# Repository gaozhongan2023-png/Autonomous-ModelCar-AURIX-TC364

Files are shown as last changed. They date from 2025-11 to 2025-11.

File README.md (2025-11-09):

# Autonomous-ModelCar-AURIX-TC364

A high-speed autonomous model car project based on the Infineon AURIX TC364 microcontroller.  
The system performs real-time lane detection, path fitting, and closed-loop PID control using onboard image processing, achieving stable tracking at speeds up to **3.3 m/s**.

---

## Project Overview

This project was developed for a vision-based autonomous car competition.  
The model car (approximately 25 cm in length) drives on a track resembling real road lanes.  
It detects both left and right lane boundaries using a custom image processing algorithm and performs high-speed closed-loop control completely offline on the MCU.

The same algorithm can also be simulated on a PC using OpenCV for debugging and visualization.

---

## Demonstration

**1. Real Vehicle Running on Track**

<p align="center">
  
</p>

**2. PC Simulation Visualization**

<p align="center">
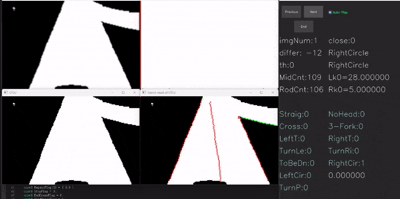
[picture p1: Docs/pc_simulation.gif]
  
</p>

---

## Repository Structure

| Directory / File | Description |
|---|---|
| **Docs/** | Supporting materials |
| `Docs/real_car.gif` | Real car driving demonstration |
| `Docs/pc_simulation.gif` | OpenCV simulation demonstration |
| **MCU/** | Embedded control code for Infineon AURIX TC364 |
| `MCU/CODE/` | User-written application logic: control algorithms, image processing, PID routines |
| `MCU/Libraries/` | Hardware abstraction and peripheral drivers (GPIO, PWM, ADC, CAN, UART, etc.) |
| `MCU/USER/` | Multi-core startup code (CPU0, CPU1) and interrupt service routines (ISR) |
| `MCU/settings/` | IDE configuration folder generated by AURIX Development Studio |
| `MCU/README.md` | Detailed MCU documentation |
| **PC_OpenCV/** | OpenCV-based simulation and visualization |
| `PC_OpenCV/imageDeal/` | PC-side algorithm implementation |
| `PC_OpenCV/imageDeal/main.cpp` | Entry point. Starts image sequence simulation and processing |
| `PC_OpenCV/imageDeal/imageDeal.cpp` | Core image processing module integrating preprocessing and lane detection |
| `PC_OpenCV/imageDeal/imagePreDeal.cpp` | Preprocessing functions (noise filtering, ROI selection, thresholding). Slightly different from MCU but equivalent results |
| `PC_OpenCV/imageDeal/Track.cpp` | Portable tracking algorithm, identical to MCU code for lane fitting |
| `PC_OpenCV/imageDeal/ui.cpp` | Visualization interface for debugging and intermediate variables |
| `PC_OpenCV/image/` | Input image sequence for testing (e.g., 0.bmp, 1.bmp, ...) |
| `PC_OpenCV/opencv_world454.rar` | OpenCV 4.5.4 runtime library (compressed) |
| `PC_OpenCV/x64/Debug/` | Debug build files (if any) |
| `PC_OpenCV/OpenCVProjectTemplate.sln` | Visual Studio solution |
| `PC_OpenCV/OpenCVProjectTemplate.vcxproj` | Visual Studio project file |
| `PC_OpenCV/OpenCVProjectTemplate.vcxproj.filters` | Visual Studio filters file |
| `PC_OpenCV/OpenCVProjectTemplate.vcxproj.user` | Visual Studio user settings file |
| `PC_OpenCV/README.md` | PC simulation documentation |
| **PCB/** | PCB design files for the model car |
| `PCB/<project_files>` | Altium Designer PCB project files (schematics, board layout, etc.) |
| **README.md** | Main project overview |
| **LICENSE** | MIT License file |
| **.gitignore** | Git ignore configuration |

---

## Technologies Used

| Component | Technology / Tool |
|---|---|
| MCU | Infineon AURIX TC364 |
| Image Sensor | MT9V034 Global Shutter Camera |
| Communication | ESP8266 WiFi |
| Image Processing | Otsu Binarization, Dual Lane Edge Detection, Line Fitting |
| Control | PID Closed-loop Steering |
| PC Framework | OpenCV (C++/Python) |
| IDE | AURIX Development Studio |

---

## Performance

- Model car length: ~25 cm  
- Maximum stable speed: **3.3 m/s**  
- Lane detection latency: < 20 ms per frame  
- Control loop frequency: 100 Hz  

---

## License

This project is released under the **MIT License**.

---

## Author

**Zhongan Gao (高钟安)**

---

## Achievements
This project won the **National Second Prize** in the **17th National Undergraduate Intelligent Vehicle Competition (全国大学生智能汽车竞赛)**, China.  

---

## Acknowledgments
Special thanks to **Yue Yang (杨越)** and **Hongyu Shi (史弘宇)** for their collaboration, contribution, and dedication throughout the project.

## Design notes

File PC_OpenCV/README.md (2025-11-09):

# PC OpenCV Debug and Simulation Platform

This module provides an offline OpenCV-based simulation environment for developing and debugging the image processing algorithm used in the AURIX Line Following Car project.

It replicates the exact same lane detection and center fitting logic as used in the MCU firmware, allowing visualization, parameter tuning, and intermediate value inspection.

---

## Dependencies

This project uses OpenCV 4.5.4 for image processing.

To reduce repository size, the required OpenCV runtime libraries are provided as a compressed file:

**opencv_world454.rar

---

## File Structure

| File / Directory | Description |
|---|---|
| **imageDeal/main.cpp** | Entry point, starts image sequence simulation and processing |
| **imageDeal/imageDeal.cpp** | Core image processing module integrating preprocessing and lane detection |
| **imageDeal/imagePreDeal.cpp**| Preprocessing functions (noise filtering, ROI selection, thresholding). Slightly different from MCU but produces equivalent results |
| **imageDeal/Track.cpp** | Portable tracking algorithm, identical to MCU code for lane fitting and deviation calculation |
| **imageDeal/ui.cpp** | Custom visualization interface for debugging and displaying intermediate variables |
| **image/** | Input image sequence for testing (0.bmp, 1.bmp, ...) |
| **opencv_world454.rar** | Compressed OpenCV 4.5.4 runtime library. Extract in current folder before running |
| **x64/Debug/** | Debug build output files |
| **OpenCVProjectTemplate.sln / .vcxproj** | Visual Studio project and solution files |
| **README.md** | Documentation for PC simulation |

---

## Framework Reference

This simulation framework is based on the open-source project:  
https://github.com/w1oves/imageDeal

The code structure has been extended and optimized to fully replicate the embedded environment of the AURIX MCU for debugging and testing purposes.

---

## Input Data

Place the image sequence to be processed in the `/image/` folder at the root of the project.  
Files should be named in numerical order, for example:

image/
├── 0.bmp
├── 1.bmp
├── 2.bmp
└── ...

---

## How to Run

1. **Extract `opencv_world454.rar`** in the current folder (`PC_OpenCV/`).  
2. run `OpenCVProjectTemplate.sln` (no additional dependencies are required).  
3. Run the project using the local Windows debugger (Start Debugging / F5) — no additional dependencies are required.
4. The program automatically loads the images from the `/image/` folder.  
5. Each frame will go through:
   - Preprocessing (grayscale conversion, filtering, binarization)
   - Lane edge scanning
   - Center line fitting
   - Visualization and debugging interface

The result simulates how the MCU performs onboard image processing during real-time driving.

---

## Features

- Identical lane detection and center fitting algorithm as MCU firmware  
- Quick testing of new thresholding or fitting strategies  
- Real-time visualization of intermediate variables (via `ui.cpp`)  
- No external OpenCV dependency required — already integrated in the project  

---

## Notes

- Designed for debugging algorithm performance offline before MCU deployment.  
- The difference between PC and MCU implementations lies only in data types and preprocessing routines.  
- For portability, ensure that all algorithm functions in `Track.cpp` remain platform-independent.

---

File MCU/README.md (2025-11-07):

# Autonomous-ModelCar-AURIX-TC364

This project is an embedded control system based on the **Infineon AURIX™ TC364 MCU**, developed and built in **AURIX Development Studio (ADS)**.  
The system enables a fully autonomous model car capable of high-speed closed-loop operation without any external computing device.

---

## Overview
During actual operation, the **TC364 MCU** runs fully offline, performing all control tasks in real time.  
At each frame, the onboard **MT9V034 camera** captures grayscale image data, which is processed through a custom image-processing pipeline:

1. **Image Binarization:** Otsu’s thresholding method is applied to segment the track.  
2. **Road Edge Detection:** Custom line-scanning algorithms detect the left and right lane boundaries.  
3. **Centerline Fitting:** The midpoint path is fitted from the detected edges.  
4. **Deviation Calculation:** The lateral offset between the vehicle and the ideal track centerline is computed.  
5. **Control Output:** A PID controller converts this deviation into corresponding PWM signals to drive the steering and throttle motors.

This enables the model car to maintain stable high-speed autonomous driving on the track, with a top speed up to **3.3 m/s**.

---

## Project Structure

| Directory / File | Description |
|---|---|
| **CODE/** | User-written application logic: control algorithms, image processing, and PID routines |
| **Libraries/** | Hardware abstraction and peripheral drivers (GPIO, PWM, ADC, CAN, UART, etc.) |
| **USER/** | Multi-core startup code (CPU0, CPU1) and interrupt service routines (ISR) |
| **.settings/** | IDE configuration folder generated by AURIX Development Studio |
| **.project / .cproject** | Project descriptor files used by the IDE for build configuration |
| **Lcf_Tasking_Tricore_Tc.lsl** | Linker script defining memory layout and section mapping |
| **LICENSE** | License file |
| **README.md** | Project documentation (this file) |

---

## CODE Directory Details

| File | Description |
|---|---|
| **ESP8266.c / ESP8266.h** | Handles serial communication with the PC via the ESP8266 Wi-Fi module for real-time image transmission. |
| **HCl.c / HCl.h** | Implements human–machine interface (HMI) functions on the LCD display. |
| **IPS.c / IPS.h** | LCD driver and display control routines. |
| **Key.c / Key.h** | Button input and on-device control logic for parameter adjustment. |
| **Motor.c / Motor.h** | Motor control routines using PID algorithms for steering and throttle output. |
| **parm.c / parm.h** | Parameter definition, tuning, and configuration management for the PID controller. |
| **PreDeal.c / PreDeal.h** | Image pre-processing, noise filtering, and normalization before binary segmentation. |
| **Track.c / Track.h** | Core image-processing and path-planning logic; includes binary image processing, lane detection, and trajectory fitting (approx. 10,000 lines of code). |

---

## Development Environment
- **IDE:** AURIX Development Studio  
- **Toolchain:** TASKING Tricore v6.x or later  
- **Target MCU:** AURIX™ TC364  
- **Language:** C  

---

## How to Build and Run
1. Open **AURIX Development Studio**  
2. Go to **Import → Existing Projects into Workspace**  
3. Select this project directory and import it  
4. Connect the **Infineon MiniWiggler** or equivalent debugger  
5. Build and flash the program to the target board  

---

## Achievements
This project won the **National Second Prize** in the **17th National Undergraduate Intelligent Vehicle Competition (全国大学生智能汽车竞赛)**, China.  

---

## Acknowledgments
Special thanks to **Yue Yang (杨越)** and **Hongyu Shi (史弘宇)** for their collaboration, contribution, and dedication throughout the project.

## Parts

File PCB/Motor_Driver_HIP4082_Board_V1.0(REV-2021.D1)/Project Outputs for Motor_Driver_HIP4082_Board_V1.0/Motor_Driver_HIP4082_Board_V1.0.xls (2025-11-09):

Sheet: BOM Report
Bill of Materials |  |  | Bill of Materials for PCB Document [Motor_Driver_HIP4082_Board_V1.0.PcbDoc]
Source Data From: |  | Motor_Driver_HIP4082_Board_V1.0.PcbDoc
Project: |  | Motor_Driver_HIP4082_Board_V1.0.PrjPcb
Variant: |  | None
Creation Date: | 2021/12/22 | 19:23
Print Date: | 44552 | 44552.80773
Footprint | Comment | LibRef | Designator | Description | Quantity
0805_LED_S1 |  | LED | 5V, 7.2V, 12V |  | 3
RB.2/.4 | 470uF/25V | CAPACITOR | C00 | Capacitor | 1
0805C | 100nF | CAP | C01 | Capacitor | 1
0603_C | 100nF | CAP | C10 | Capacitor | 1
3528 |  | Cap Pol3 | C20, C21 | Polarized Capacitor (Surface Mount) | 2
0603C | 1uF | CAP | C30, C31 | Capacitor | 2
0603_C | 1uF | CAP | C40, C41 | Capacitor | 2
SOD-323 | 1N5819 | DIODE SCHOTTKY | D30, D31, D32, D33, D34, D35, D40, D41, D42, D43, D44, D45 | Schottky Diode | 12
SIP6N | HEADER 6 | HEADER 6 | JP1 |  | 1
KF301-2P | HEADER 2 | HEADER 2 | JP2, Motor2, Motor 1 |  | 3
KEY_7V2 | SS-12F23 | SSW-1P | KEY_7V2 | 1路波动开关 | 1
LR7843 | IR7843 | MOSFET-N | Q30, Q31, Q32, Q33, Q40, Q41, Q42, Q43 | N-Channel MOSFET | 8
0603_R | 4.7K | RES2 | R0, R1, R2 |  | 3
805 | 0 | RES2 | R3 |  | 1
0603_R | 10K | RES2 | R10, R11, R12, R13, R34, R44 |  | 6
805 | 20 | RES2 | R30, R31, R32, R33, R40, R41, R42, R43 |  | 8
SOP20 | 74HC245 | 74HC245 | U1 |  | 1
SIP4_B_S-1W | B0512S-1W | 4 HEADER | U2 | 4 Pin Header | 1
SOP-16_208mil | HIP4082 | HIP4082 | U3, U4 |  | 2
 |  |  |  |  | 59
Approved |  | Notes

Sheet: Project Information
Project Full Path | C:\Users\Kanesh's laptop\Desktop\Motor_Driver_HIP4082_Board_V1.0(REV-2021.D1)\Motor_Driver_HIP4082_Board_V1.0.PrjPcb
Project Filename | Motor_Driver_HIP4082_Board_V1.0.PrjPcb
Variant Name | None
Data-Source Filename | Motor_Driver_HIP4082_Board_V1.0.PcbDoc
Data-Source Full Path | C:\Users\Kanesh's laptop\Desktop\Motor_Driver_HIP4082_Board_V1.0(REV-2021.D1)\Motor_Driver_HIP4082_Board_V1.0.PcbDoc
Title | Bill of Materials for PCB Document [Motor_Driver_HIP4082_Board_V1.0.PcbDoc]
Total Quantity | 59
Report Time | 19:23
Report Date | 2021/12/22
Report Date & Tine | 2021/12/22 19:23
Output Name | Bill of Materials
Output Type | BOM_PartType
Output Generator Name | BOM
Output Generator Description | Bill of Materials

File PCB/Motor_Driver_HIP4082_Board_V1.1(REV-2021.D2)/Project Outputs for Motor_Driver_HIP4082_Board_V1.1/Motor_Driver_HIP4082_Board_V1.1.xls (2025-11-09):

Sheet: BOM Report
Bill of Materials |  |  | Bill of Materials for PCB Document [Motor_Driver_HIP4082_Board_V1.1.PcbDoc]
Source Data From: |  | Motor_Driver_HIP4082_Board_V1.1.PcbDoc
Project: |  | Motor_Driver_HIP4082_Board_V1.1.PrjPcb
Variant: |  | None
Creation Date: | 2021/12/30 | 14:22
Print Date: | 44560 | 44560.59869
Footprint | Comment | LibRef | Designator | Description | Quantity
0805_LED_S1 |  | LED | 5V, 7.2V, 12V |  | 3
RB.2/.4 | 470uF/25V | CAPACITOR | C00 | Capacitor | 1
0805C | 100nF | CAP | C01, C10 | Capacitor | 2
3528 |  | Cap Pol3 | C20, C21 | Polarized Capacitor (Surface Mount) | 2
0805C | 1uF | CAP | C30, C31, C40, C41 | Capacitor | 4
SOD-323 | 1N5819 | DIODE SCHOTTKY | D30, D31, D32, D33, D34, D35, D40, D41, D42, D43, D44, D45 | Schottky Diode | 12
SIP6N | HEADER 6 | HEADER 6 | JP1 |  | 1
KF301-2P | HEADER 2 | HEADER 2 | JP2, Motor2, Motor 1 |  | 3
LR7843 | IR7843 | MOSFET-N | Q30, Q31, Q32, Q33, Q40, Q41, Q42, Q43 | N-Channel MOSFET | 8
0603_R | 4.7K | RES2 | R0, R1, R2 |  | 3
0805R | 0 | RES2 | R3 |  | 1
0603_R | 10K | RES2 | R10, R11, R12, R13, R34, R44 |  | 6
805 | 20 | RES2 | R30, R31, R32, R33, R40, R41, R42, R43 |  | 8
KEY-3P | Header 3 | Header 3 | SWITCH | Header, 3-Pin | 1
SOP20 | 74HC245 | 74HC245 | U1 |  | 1
SIP4_B_S-1W | B0512S-1W | 4 HEADER | U2 | 4 Pin Header | 1
SOP-16_208mil | HIP4082 | HIP4082 | U3, U4 |  | 2
 |  |  |  |  | 59
Approved |  | Notes

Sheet: Project Information
Project Full Path | C:\Users\Kanesh's laptop\Desktop\17届智能车\硬件工程\Motor_Driver_HIP4082_Board_V1.1(REV-2021.D2)\Motor_Driver_HIP4082_Board_V1.1.PrjPcb
Project Filename | Motor_Driver_HIP4082_Board_V1.1.PrjPcb
Variant Name | None
Data-Source Filename | Motor_Driver_HIP4082_Board_V1.1.PcbDoc
Data-Source Full Path | C:\Users\Kanesh's laptop\Desktop\17届智能车\硬件工程\Motor_Driver_HIP4082_Board_V1.1(REV-2021.D2)\Motor_Driver_HIP4082_Board_V1.1.PcbDoc
Title | Bill of Materials for PCB Document [Motor_Driver_HIP4082_Board_V1.1.PcbDoc]
Total Quantity | 59
Report Time | 14:22
Report Date | 2021/12/30
Report Date & Tine | 2021/12/30 14:22
Output Name | Bill of Materials
Output Type | BOM_PartType
Output Generator Name | BOM
Output Generator Description | Bill of Materials

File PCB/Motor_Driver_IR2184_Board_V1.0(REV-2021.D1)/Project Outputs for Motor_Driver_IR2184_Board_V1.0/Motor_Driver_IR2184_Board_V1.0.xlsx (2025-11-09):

Comment | Description | Designator | Footprint | LibRef | Quantity
 |  | 5V, 7.2V, 17V | 0805_LED_S1 | LED | 3
470uF/25V | Capacitor | C00 | RB.2/.4 | CAPACITOR | 1
100nF | Capacitor | C01, C10, C30, C40, C50, C60 | 0805C | CAP | 6
 | Polarized Capacitor (Surface Mount) | C20, C21 | 3528 | Cap Pol3 | 2
10uF/35V | Capacitor | C31, C41, C51, C61 | 3528 | CAPACITOR | 4
1N5819 | Default Diode, Schottky Diode | D10, D11, D20, D21, D30, D31, D32, D33, D40, D41, D42, D43 | SOD-323 | Diode, DIODE SCHOTTKY | 12
HEADER 6 |  | JP1 | SIP6N | HEADER 6 | 1
HEADER 2 |  | JP2, Motor2, Motor 1 | KF301-2P | HEADER 2 | 3
6.8uH |  | L1, L2 | 1206_L | INDUCTOR2 | 2
IR7843 | N-Channel MOSFET | Q30, Q31, Q32, Q33, Q40, Q41, Q42, Q43 | LR7843 | MOSFET-N | 8
4.7K |  | R0, R1, R2 | 0603_R | RES2 | 3
0 |  | R3 | 0805R | RES2 | 1
10K |  | R10, R11, R12, R13 | 0603_R | RES2 | 4
20 |  | R30, R31, R32, R33, R40, R41, R42, R43 | 0805 | RES2 | 8
Header 3 | Header, 3-Pin | SWITCH | KEY-3P | Header 3 | 1
74HC245 |  | U1 | SOP20 | 74HC245 | 1
B0512S-1W | 4 Pin Header | U2 | SIP4_B_S-1W | 4 HEADER | 1
IR2184 |  | U3, U4, U5, U6 | SO-8 | IR2184 | 4

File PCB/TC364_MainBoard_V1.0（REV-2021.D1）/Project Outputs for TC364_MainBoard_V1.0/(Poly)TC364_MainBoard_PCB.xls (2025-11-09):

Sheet: BOM Report
Bill of Materials |  |  | Bill of Materials For PCB Document [(Poly)TC364_MainBoard_PCB.PcbDoc]
Source Data From: |  | (Poly)TC364_MainBoard_PCB.PcbDoc
Project: |  | TC364_MainBoard_V1.0.PrjPcb
Variant: |  | None
Creation Date: | 2021/12/9 | 16:49:37
Print Date: | 44539 | 44539.70133
Footprint | Comment | LibRef | Designator | Description | Quantity
CAP 3.5*8*11.5 - GD | 680uF/16V | Cap Pol1 | C01 | Polarized Capacitor (Radial) | 1
0805_C | 0.1uF | CAP | C02, C03, C12, C14, C22, C24, C32, C34, C42, C44 | Capacitor | 10
CASE-A_3216 | 10uF/16V | Cap Pol1 | C11, C13, C31, C33, C41, C43 | Polarized Capacitor (Radial) | 6
CAP 2.5*6.3*11.2 - BK | 330uF/16V | Cap Pol1 | C21, C23 | Polarized Capacitor (Radial) | 2
SMA | SS54 | SS34 | D21 | 肖特基二极管 | 1
HOLE-3.5 | Comment |  | Designator455, Designator456, Designator457, Designator458 |  | 4
0805_LED_S1 | LED | LED | D_3V3, D_5V, D_5V5, D_CAM | 发光二极管 | 4
SIP8 | HDR-1X7 | HEADER 8 | JP_20602, JP_IPS | 8 Pin Header | 2
IDC16-JLC - duplicate | HEADER 8X2 | HEADER 8X2 | JP_Camera |  | 1
HDR2.54-LI-2x3P | Header3X2 | Header 3X2 | JP_Code1, JP_Code2 | 3*2P接插件 | 2
HDR2.54-LI-3P | HDR-1X3 | Header 3 | JP_GP2Y, JP_Steer | 3P接插件 | 2
SIP6N | HDR-1X6 | HEADER 6 | JP_Motor |  | 1
IDC10-JLC | HEADER 5X2 | HEADER 5X2 | JP_W2UART |  | 1
KEY_7V2 | SS-12F23 | SSW-1P | KEY_7V2 | 1路波动开关 | 1
7*7 L | 33uH | L-CDRH | L21 | 功率屏蔽电感 | 1
T_Type_Adapter | T_Type_Adapter | T_Type_Adapter | P_7V2 |  | 1
PNP8550-SO | PNP8550 | PNP | Q1 | PNP Transistor | 1
0805_R | 200K | RES | R01 |  | 1
0805_R | 100K | RES | R02 |  | 1
0805_R | 1K | RES | R03 |  | 1
0805_R | 4.7K | RES | R11, R25, R31, R41 |  | 4
0603_R | 1K | RES | R21 | 贴片电阻 | 1
0603_R | 2.7K | RES | R22 | 贴片电阻 | 1
0603_R | 3.9K | RES | R23 | 贴片电阻 | 1
0603_R | 22K | RES | R24 | 贴片电阻 | 1
0805_R | 0 | RES | R26, R42 |  | 2
KEY2-6X3 | SW-PB | SW-PB | S1, S2, S3, S4, S5, S6 | 按键 | 6
CSW DIP-4P | SW-4P | SW-4P | S7 | 4路编码开关 | 1
TO-220(TO-220-3) | SPX2940-5.0V | LM2940 | U1 | 5V稳压芯片 | 1
SOP-8_150mil | AS1015 | AS1015 | U2 | 可调升压芯片 | 1
SOT-23-5 | RT9013-3.3 | RT9013-3.3 | U3, U4 |  | 2
TC364_CoreBoard | TC364_CoreBoard | TC264_CoreBoard | U5 | 逐飞科技TC264核心板 | 1
BUZ | BEEP | BELL | U6 | Bell | 1
 |  |  |  |  | 67
Approved |  | Notes

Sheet: Project Information
Project Full Path | C:\Users\Kanesh's laptop\Desktop\TC364_MainBoard_V1.0（REV-2021.D1）\TC364_MainBoard_V1.0.PrjPcb
Project Filename | TC364_MainBoard_V1.0.PrjPcb
Variant Name | None
Data-Source Filename | (Poly)TC364_MainBoard_PCB.PcbDoc
Data-Source Full Path | C:\Users\Kanesh's laptop\Desktop\TC364_MainBoard_V1.0（REV-2021.D1）\(Poly)TC364_MainBoard_PCB.PcbDoc
Title | Bill of Materials For PCB Document [(Poly)TC364_MainBoard_PCB.PcbDoc]
Total Quantity | 67
Report Time | 16:49:37
Report Date | 2021/12/9
Report Date & Tine | 2021/12/9 16:49:37
Output Name | Bill of Materials
Output Type | BOM_PartType
Output Generator Name | BOM
Output Generator Description | Bill of Materials

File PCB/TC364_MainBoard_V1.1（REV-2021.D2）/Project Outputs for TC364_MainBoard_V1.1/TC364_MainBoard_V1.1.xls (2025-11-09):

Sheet: BOM Report
Bill of Materials |  |  | Bill of Materials for PCB Document [(Poly)TC364_MainBoard_PCB_V1.1.PcbDoc]
Source Data From: |  | (Poly)TC364_MainBoard_PCB_V1.1.PcbDoc
Project: |  | TC364_MainBoard_V1.1.PrjPcb
Variant: |  | None
Creation Date: | 2021/12/14 | 16:30
Print Date: | 44544 | 44544.68815
Footprint | Comment | LibRef | Designator | Description | Quantity
7*7 L | 33uH | L-CDRH | L21 | 功率屏蔽电感 | 1
0603_R | 1K | RES | R03, R21 | [NoValue], 贴片电阻 | 2
0603_R | 2.7K | RES | R22 | 贴片电阻 | 1
0603_R | 3.9K | RES | R23 | 贴片电阻 | 1
0603_R | 4.7K | RES | R11, R25, R31, R41, R51 |  | 5
0603_R | 22K | RES | R24 | 贴片电阻 | 1
0603_R | 100K | RES | R02 |  | 1
0603_R | 200K | RES | R01 |  | 1
0603C | 0.1uF | CAP | C02, C03, C12, C14, C22, C24, C32, C34, C42, C44, C52, C54 | Capacitor | 12
0805_LED_S1 | LED | LED | D_3V3, D_5V, D_5V5, D_CAM, D_MCU | 发光二极管 | 5
0805_R | 0 | RES | R26, R42, R52 |  | 3
BUZ | BEEP | BELL | U6 | Bell | 1
Camera-Port | FPC05-18 | FPC05-18 | JP_Camera |  | 1
CAP 2.5*6.3*11.2 - BK | 330uF/16V | Cap Pol1 | C21, C23 | Polarized Capacitor (Radial) | 2
CAP 3.5*8*11.5 - GD | 680uF/16V | Cap Pol1 | C01 | Polarized Capacitor (Radial) | 1
CASE-A_3216 | 10uF/16V | Cap Pol1 | C11, C13, C31, C33, C41, C43, C51, C53 | Polarized Capacitor (Radial) | 8
CSW DIP-4P | SW-4P | SW-4P | S7 | 4路编码开关 | 1
HDR2.54-LI-2x3P | Header3X2 | Header 3X2 | JP_Code1, JP_Code2 | 3*2P接插件 | 2
HDR2.54-LI-3P | HDR-1X3 | Header 3 | JP_Steer | 3P接插件 | 1
IDC10-JLC | HEADER 5X2 | HEADER 5X2 | JP_W2UART |  | 1
KEY2-6X3 | SW-PB | SW-PB | S1, S2, S3, S4, S5, S6 | 按键 | 6
KEY_7V2 | SS-12F23 | SSW-1P | KEY_7V2 | 1路波动开关 | 1
KF301-2P | KCF301 | KCF301 |  |  | 1
PNP8550-SO | PNP8550 | PNP | Q1 | PNP Transistor | 1
SIP3N | HDR-1X3 | Header 3 | JP_GP2Y | 3P接插件 | 1
SIP6N | HDR-1X6 | HEADER 6 | JP_Motor |  | 1
SIP8 | HDR-1X7 | HEADER 8 | JP_20602, JP_IPS | 8 Pin Header | 2
SMA | SS54 | SS34 | D21 | 肖特基二极管 | 1
SOP-8_150mil | AS1015 | AS1015 | U2 | 可调升压芯片 | 1
SOT-23-5 | RT9013-3.3 | RT9013-3.3 | U3, U4, U5 |  | 3
T_Type_Adapter | T_Type_Adapter | T_Type_Adapter | P_7V2 |  | 1
TC364 | LQ-TC264-SYSVC | LQ-TC264-SYSVC | LQ-TC264-SYSVC |  | 1
TO-220(TO-220-3) | SPX2940-5.0V | LM2940 | U1 | 5V稳压芯片 | 1
 |  |  |  |  | 72
Approved |  | Notes

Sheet: Project Information
Project Full Path | C:\Users\Kanesh's laptop\Desktop\TC364_MainBoard_V1.1（REV-2021.D2）\TC364_MainBoard_V1.1.PrjPcb
Project Filename | TC364_MainBoard_V1.1.PrjPcb
Variant Name | None
Data-Source Filename | (Poly)TC364_MainBoard_PCB_V1.1.PcbDoc
Data-Source Full Path | C:\Users\Kanesh's laptop\Desktop\TC364_MainBoard_V1.1（REV-2021.D2）\(Poly)TC364_MainBoard_PCB_V1.1.PcbDoc
Title | Bill of Materials for PCB Document [(Poly)TC364_MainBoard_PCB_V1.1.PcbDoc]
Total Quantity | 72
Report Time | 16:30
Report Date | 2021/12/14
Report Date & Tine | 2021/12/14 16:30
Output Name | Bill of Materials
Output Type | BOM_PartType
Output Generator Name | BOM
Output Generator Description | Bill of Materials

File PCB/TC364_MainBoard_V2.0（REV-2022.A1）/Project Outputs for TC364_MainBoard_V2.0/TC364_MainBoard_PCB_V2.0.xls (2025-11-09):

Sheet: BOM Report
Bill of Materials |  |  | Bill of Materials For PCB Document [TC364_MainBoard_PCB_V2.0.PcbDoc]
Source Data From: |  | TC364_MainBoard_PCB_V2.0.PcbDoc
Project: |  | TC364_MainBoard_V2.0.PrjPcb
Variant: |  | None
Creation Date: | 2022/2/16 | 19:30:32
Print Date: | 44608 | 44608.81297
Footprint | Comment | LibRef | Designator | Description | Quantity
7*7 L | 33uH | L-CDRH | L21 | 功率屏蔽电感 | 1
0805C | 0.1uF | CAP | C02, C03, C12, C14, C22, C24, C32, C34, C42, C44, C52, C54, C72, C74 | Capacitor | 14
0805R | 0 | RES | R26, R42, R52 |  | 3
0805R | 100K | RES | R02 |  | 1
0805R | 1K | RES | R03, R21 | [NoValue], 贴片电阻 | 2
0805R | 2.7K | RES | R22 | 贴片电阻 | 1
0805R | 200K | RES | R01 |  | 1
0805R | 22K | RES | R24 | 贴片电阻 | 1
0805R | 3.9K | RES | R23 | 贴片电阻 | 1
0805R | 4.7K | RES | R11, R25, R31, R41, R51, R71 |  | 6
0805_LED_S1 | LED | LED | D_3V3, D_5V, D_5V5, D_CAM, D_MCU, D_UART | 发光二极管 | 6
BUZ | BUZ | BELL | U6 | Bell | 1
CAP 2.5*6.3*11.2 - BK | 330uF/16V | Cap Pol1 | C21, C23 | Polarized Capacitor (Radial) | 2
CAP 3.5*8*11.5 - GD | 680uF/16V | Cap Pol1 | C01 | Polarized Capacitor (Radial) | 1
CASE-A_3216 | 10uF/16V | Cap Pol1 | C11, C13, C31, C33, C41, C43, C51, C53, C71, C73 | Polarized Capacitor (Radial) | 10
CSW DIP-4P | SW-4P | SW-4P | S7 | 4路编码开关 | 1
HDR2.54-LI-2x3P | Header3X2 | Header 3X2 | JP_Code1, JP_Code2 | 3*2P接插件 | 2
HDR2.54-LI-3P | HDR-1X3 | Header 3 | JP_Steer | 3P接插件 | 1
IDC10-JLC | HEADER 5X2 | HEADER 5X2 | JP_W2UART |  | 1
IDC16-JLC - duplicate | HEADER 8X2 | HEADER 8X2 | JP_Camera |  | 1
KEY2-6X3 | SW-PB | SW-PB | S1, S2, S3, S4, S5, S6 | 按键 | 6
KEY_7V2 | SS-12F23 | SSW-1P | KEY_7V2 | 1路波动开关 | 1
KF301-2P | KCF301 | KCF301 |  |  | 1
PNP8550-SO | PNP8550 | PNP | Q1 | PNP Transistor | 1
SIP3N | HDR-1X3 | Header 3 | JP_GP2Y | 3P接插件 | 1
SIP6N | HDR-1X6 | HEADER 6 | JP_Motor |  | 1
SIP8 | HDR-1X7 | HEADER 8 | JP_20602, JP_IPS | 8 Pin Header | 2
SMA | SS54 | SS34 | D21 | 肖特基二极管 | 1
SOP-8_150mil | AS1015 | AS1015 | U2 | 可调升压芯片 | 1
SOT-23-5 | RT9013-3.3 | RT9013-3.3 | U3, U4, U5 |  | 3
TC364V1.2 | LQ-TC264-SYSVC | LQ-TC264-SYSVC | LQ-TC264-SYSVC |  | 1
TO-220(TO-220-3) | SPX2940-5.0V | LM2940 | U1, U7 | 5V稳压芯片 | 2
T_Type_Adapter | T_Type_Adapter | T_Type_Adapter | P_7V2 |  | 1
 |  |  |  |  | 79
Approved |  | Notes

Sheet: Project Information
Project Full Path | C:\Users\YangYue\Desktop\寒假工作\主板\1.2\TC364_MainBoard_V1.3\TC364_MainBoard_V2.0.PrjPcb
Project Filename | TC364_MainBoard_V2.0.PrjPcb
Variant Name | None
Data-Source Filename | TC364_MainBoard_PCB_V2.0.PcbDoc
Data-Source Full Path | C:\Users\YangYue\Desktop\寒假工作\主板\1.2\TC364_MainBoard_V1.3\TC364_MainBoard_PCB_V2.0.PcbDoc
Title | Bill of Materials For PCB Document [TC364_MainBoard_PCB_V2.0.PcbDoc]
Total Quantity | 79
Report Time | 19:30:32
Report Date | 2022/2/16
Report Date & Tine | 2022/2/16 19:30:32
Output Name | Bill of Materials
Output Type | BOM_PartType
Output Generator Name | BOM
Output Generator Description | Bill of Materials

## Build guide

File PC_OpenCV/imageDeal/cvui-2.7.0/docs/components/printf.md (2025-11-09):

---
layout: default
title: printf
---

# printf

`cvui::printf()` renders a piece of text that can be formatted using C `printf()` style. The signature of the function is:

```cpp
void printf(cv::Mat& theWhere, int theX, int theY, const char *theFmt, ...);
```

where `theWhere` is the image/frame where the image will be rendered, `theX` is the position X, `theY` is the position Y, `theFmt` is the formating string as it would be supplied for `stdio's printf()`, e.g. `"Text: %d and %f", 7, 3.1415`.

`cvui::printf()` is used pretty much as C's `printf()` function. Below is an example of the component, whose result on the screen is shown in Figure 1.

```cpp
double value = 3.14;
cvui::printf(frame, 90, 50, "value = %.2f", value);
```

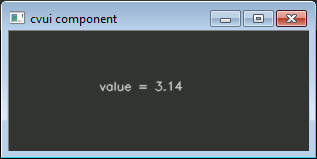
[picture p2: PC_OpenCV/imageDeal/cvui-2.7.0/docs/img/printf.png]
printf component

<p class="img-caption">Figure 1: printf component.</p>

## Text size and color

It is possible to customize the size and color of the text produced by `cvui::printf()`. The following function signature can be used in that case:

```cpp
void printf (
    cv::Mat& theWhere,
    int theX,
    int theY,
    double theFontScale,
    unsigned int theColor,
    const char *theFmt,
    ...
);
```

where `theWhere` is the image/frame where the image will be rendered, `theX` is the position X, `theY` is the position Y, `theFontScale` is the size of the text, `theColor` is the color of the text in the format `0xRRGGBB`, e.g. `0xff0000` for red, and `theFmt` is the formating string as it would be supplied for `stdio's printf()`, e.g. `"Text: %d and %f", 7, 3.1415`.

Below is an example of a text with customized size and color. Result on the screen is shown in Figure 2.

```cpp
double value = 3.14;
cvui::printf(frame, 90, 50, 0.8, 0x00ff00, "value = %.2f", value);
```

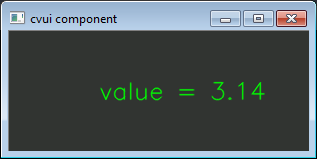
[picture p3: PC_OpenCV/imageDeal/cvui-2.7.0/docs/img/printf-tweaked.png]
printf with customized size and color

<p class="img-caption">Figure 2: text with customized size and color.</p>

## Learn more

Check the [main-app](https://github.com/Dovyski/cvui/tree/master/example/src/main-app) example for more information about <code>cvui::printf()</code>.

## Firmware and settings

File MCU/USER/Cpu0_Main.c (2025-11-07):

/*********************************************************************************************************************
 * COPYRIGHT NOTICE
 * Copyright (c) 2020,逐飞科技
 * All rights reserved.
 * 技术讨论QQ群：三群：824575535
 *
 * 以下所有内容版权均属逐飞科技所有，未经允许不得用于商业用途，
 * 欢迎各位使用并传播本程序，修改内容时必须保留逐飞科技的版权声明。
 *
 * @file            main
 * @company         成都逐飞科技有限公司
 * @author          逐飞科技(QQ3184284598)
 * @version         查看doc内version文件 版本说明
 * @Software        ADS v1.2.2
 * @Target core     TC364DP
 * @Taobao          https://seekfree.taobao.com/
 * @date            2020-11-23
 ********************************************************************************************************************/

#include "Cpu0_Main.h"
#include "headfile.h"
#include "HCI.h"
#include "IPS.h"
#include "Key.h"
#include "Track.h"
#include "PreDeal.h"
#include "Motor.h"
#pragma section all "cpu0_dsram"
//将本语句与#pragma section all restore语句之间的全局变量都放在CPU0的RAM中

//工程导入到软件之后，应该选中工程然后点击refresh刷新一下之后再编译

//工程默认设置为关闭优化，可以自己右击工程选择properties->C/C++ Build->Setting
//然后在右侧的窗口中找到C/C++ Compiler->Optimization->Optimization level处设置优化等级
//一般默认新建立的工程都会默认开2级优化，因此大家也可以设置为2级优化

//对于TC系列默认是不支持中断嵌套的，希望支持中断嵌套需要在中断内使用enableInterrupts();来开启中断嵌套
//简单点说实际上进入中断后TC系列的硬件自动调用了disableInterrupts();来拒绝响应任何的中断，因为需要我们自己手动调用enableInterrupts();来开启中断的响应。

extern uint16 nowtime;
extern uint16 time;
extern uint8 Thro;
extern int8 Error;
extern int8 NowError;
extern int8 CloseError;
extern uint8 RampFlag;
extern uint8 LowSpeedFlag;
extern uint8 SwitchFlag;
extern uint8 NoCircleFlag;

//uint8 Thro;
//int8 Error;
//uint16 nowtime;

extern uint8 LeftLine[256][2];
extern uint8 RightLine[256][2];
extern uint8 MiddleLine[256][2];
extern uint8 MidLine[256][2];
extern uint8 LeftTurn[4][3];
extern uint8 RightTurn[4][3];
extern uint8 TempLine1[256][2];
extern uint8 TempLine2[256][2];
uint8 testLine[120][2];

extern float LeftK[8];
extern float RightK[8];

extern uint8 CloseFlag;
extern uint8 EspFlag;
extern int8 Num[2];

extern struct imageInformation imgInfo;

extern uint32 SteerMid;

extern uint32 res1;
extern uint32 res2;
extern uint32 res3;
extern uint32 res4;
extern uint32 res5;
extern uint32 res6;
extern uint32 mid_speed;
extern uint32 high_speed;
extern uint32 PD_P;
extern uint32 b_value;
extern uint32 PD_D;

extern uint32 P_value;  //电机PID的P值
extern uint32 I_value;  //电机PID的I值
extern uint32 D_value;  //电机PID的D值

extern uint32 s_a_value;  //差速的a值
extern uint32 s_b_value;  //差速的b值
extern uint32 s_c_value;  //差速的c值

extern int Speed_pid_p, Speed_pid_i, Speed_pid_d;

extern uint8 turnpoint[3][2];

extern float PreError;
extern uint16 set_speed;
extern uint16 Steer;
extern uint8 middle;
extern int16 speed;
extern int16 ex_v1;
extern int16 ex_v2;

extern uint8 MiddleValue;
extern uint8 GarageFlag;
extern motor motor_l, motor_r;
extern pid RS_380;
extern uint8 ErrorBuffer[256];
extern uint8 StopFlag;
extern uint8 ThreeForkFlag;
extern uint8 CirCleOutFlag;
extern uint8 CircleFlag;
extern uint8 CrossFlag;
extern uint8 BadCrossFlag;
extern uint8 RightTFlag;
extern uint8 LeftTFlag;
extern float LeftCos, RightCos;
extern float increase;
extern float StraightFactor;
extern float StraightBuffer[11];
unsigned char mt9v03x_image_copy[60][94];
extern uint8 imageBin[MT9V03X_H][MT9V03X_W];

extern uint8 Mark[4];
extern uint16 BadCrossTime;
extern uint8 NoHeadFlag;
extern uint8 ThreeForkCount;
extern uint8 ThreeForkTime;

extern uint8 P1;
extern uint8 P2;
extern uint8 P3;
extern uint8 P4;
extern uint8 P5;
extern uint8 P6;
extern uint8 D1;
extern uint8 D2;
extern uint8 D3;
extern uint8 D4;
extern uint8 D5;
extern uint8 D6;

uint8 Cpu0InitFlag = 0;

extern int16 C1Num;
extern uint8 C2Num[2];
extern int8 Error5[5];
extern uint8 RepairFlag[2];
extern uint8 LeftMax;
extern uint8 RightMax;

extern float gpt_stop;
extern uint32 stop_time;

extern uint8 ThreeForkForesee[8];
extern uint8 LeftTForesee;
extern uint8 RightTForesee;
extern uint8 LeftCircleForesee;
extern uint8 RightCircleForesee;
extern uint8 LGForesee;
extern uint8 RGForesee;
extern uint8 ThreeForkOutFlag;
extern uint8 SpeedUpCount;
extern uint16 RampCount;

uint8 SceenFlag=0;

int core0_main(void)
{
    get_clk();//获取时钟频率  务必保留
    //用户在此处调用各种初始化函数等

    //目前的库采集总钻风 图像最后一列为固定的黑色
    //这是由于单片机造成的，不是摄像头的问题

    uart_init(UART_3, 115200, UART3_TX_P15_6, UART3_RX_P15_7);
    uart_putchar(UART_3, 0xfe);
    uart_putchar(UART_3, 0x10);

    icm20602_init_spi();

//    ESP8266_Init();

    adc_init(ADC_8, ADC8_CH15_A47);//初始化ADC0 通道0 使用A0引脚
    adc_init(ADC_8, ADC8_CH12_A44);//初始化ADC0 通道0 使用A0引脚
    gpio_init(P02_6, GPO, 0, OPENDRAIN);
    systick_delay_ms(STM0, 100);
    gpio_set(P02_6, 1);

//    gtm_pwm_init(ATOM0_CH7_P02_7, 100, 1522);//中1510，左1670，右，1350
    gtm_pwm_init(ATOM0_CH7_P02_7, 50, 1496/2);//中1510，左1670，右，1350

    ips114_init();  //初始化IPS屏幕
    mt9v03x_init(); //初始化摄像头
    ips114_showstr(0, 0, "SEEKFREE MT9V03x");
    ips114_showstr(0, 1, "Initializing...");

    gtm_pwm_init(ATOM0_CH0_P21_2, 10000, 0);
    gtm_pwm_init(ATOM0_CH1_P21_3, 10000, 0);
    gtm_pwm_init(ATOM0_CH4_P02_4, 10000, 0);
    gtm_pwm_init(ATOM0_CH3_P21_5, 10000, 0);

    gpt12_init(GPT12_T4, GPT12_T4INA_P02_8, GPT12_T4EUDA_P00_9);
    gpt12_init(GPT12_T6, GPT12_T6INA_P20_3, GPT12_T6EUDA_P20_0);

    Cpu0InitFlag=1;

    //等待所有核心初始化完毕
    IfxCpu_emitEvent(&g_cpuSyncEvent);
    IfxCpu_waitEvent(&g_cpuSyncEvent, 0xFFFF);
    enableInterrupts();

    Clr_Screen(8);

    HCI_init();

    HCI_handle();

    if(SWITCH_ON == SWITCH_Get_Input(SWITCH2))
    {
        ThreeForkForesee[0] = res1 / 100;
        ThreeForkForesee[1] = res1 % 100;
        ThreeForkForesee[2] = res2 / 100;
        ThreeForkForesee[3] = res2 % 100;
        LeftTForesee = res3 / 100;
        RightTForesee = res3 % 100;
        LeftCircleForesee = res4 / 100;
        RightCircleForesee = res4 % 100;
    }

    MiddleValue = 94;
    speed = (float)mid_speed/100;

    gpio_set(P02_6, 0);
    systick_delay_ms(STM0, 100);
    gpio_set(P02_6, 1);
    systick_delay_ms(STM0, 100);
    gpio_set(P02_6, 0);
    systick_delay_ms(STM0, 100);
    gpio_set(P02_6, 1);

    systick_delay_ms(STM0, 1000);

    gpio_set(P02_6, 0);
    systick_delay_ms(STM0, 400);
    gpio_set(P02_6, 1);

    ErrorInit();

    Cpu0InitFlag = 2;

    pit_interrupt_us(CCU6_0, PIT_CH0, 100);
    pit_interrupt_ms(CCU6_0, PIT_CH1, 5);
    pit_interrupt_ms(CCU6_1, PIT_CH0, 1);
    imgInfo.ThreeForkDir = 0;

    if(SWITCH_ON == SWITCH_Get_Input(SWITCH3))
    {
        imgInfo.NoHeadDir = 1;//左拐出库
    }
    else
    {
        imgInfo.NoHeadDir = 0;//右拐出库
    }

//出库！
    if(SWITCH_ON != SWITCH_Get_Input(SWITCH1))
    {
        imgInfo.roadType = NoHead;
        imgInfo.nextroadType = NoHead;
        SceenFlag = 1;
    }

//    imgInfo.roadType = Straight;
//    imgInfo.nextroadType = Straight;

    IfxScuWdt_disableCpuWatchdog(IfxScuWdt_getCpuWatchdogPassword());
    IfxScuWdt_changeCpuWatchdogReload(IfxScuWdt_getCpuWatchdogPassword(), 0xF000); /* Set CPU0WD timer to ~1.3 sec */
    IfxScuWdt_enableCpuWatchdog(IfxScuWdt_getCpuWatchdogPassword());
    IfxScuWdt_clearCpuEndinit(IfxScuWdt_getCpuWatchdogPassword());
    IfxScuWdt_serviceCpuWatchdog(IfxScuWdt_getCpuWatchdogPassword()); // 喂狗

    while (TRUE)
    {
        if(mt9v03x_finish_flag)
        {
            mt9v03x_finish_flag = 0;
            Thro = ostu();
            Binarization(Thro);
            NearScan();
            GetK();
            GetMiddle();
            RoadJudge();
            NextRoad();
            GetMid();
            SpeedUp();
            LoseLine();


            C2Num[0] = LeftLine[imgInfo.LeftLineSum][1];
            C2Num[1] = RightLine[imgInfo.RightLineSum][1];
            Error = MiddleValue - ErrorSum();

            PreError = ((float)(Error5[4]+Error5[3]+Error5[2]+Error5[1]+Error5[0]))/5;
            Error5[4] = Error5[3];
            Error5[3] = Error5[2];
            Error5[2] = Error5[1];
            Error5[1] = Error5[0];
            Error5[0] = Error;
            NowError = ((float)(Error5[4]+Error5[3]+Error5[2]+Error5[1]+Error5[0]))/5;


            nowtime = time;
            time = 0;

            if(gpt_stop == 0)
            {
                IfxScuWdt_serviceCpuWatchdog(IfxScuWdt_getCpuWatchdogPassword()); // 喂狗
            }


//            if(LeftTFlag == 2 || RightTFlag == 2)
//            {
//                Steer = (uint16)(1496 + (int16)Error*(int16)P2/10 + (NowError-PreError)*D2);
//            }
//            else if(LeftTFlag == 3 || RightTFlag == 3)
//            {
//                Steer = (uint16)(1496 + (int16)Error*(int16)P2/10 + (NowError-PreError)*D2);
//            }
////            else if(BadThreeForkFlag == 1)
////            {
////                Steer = (uint16)(1496 + (int16)Error*(int16)P3/10 + (NowError-PreError)*D3);
////            }
//            else
//            {
//                Steer = (uint16)(1496 + (int16)Error*(int16)PD_P/10 + (NowError-PreError)*PD_D);
//            }


            if(Error<0)//左
            {
                //1.7 33 15
                Steer = (uint16)(1496 + (int16)Error*(int16)P1/10 + (NowError-PreError)*D1);
            }
            else//右
            {
                //1.7 33 15
                Steer = (uint16)(1496 + (int16)Error*(int16)PD_P/10 + (NowError-PreError)*PD_D);
            }

            if(Steer>1665) Steer = 1665;
            else if(Steer<1340) Steer = 1340;

            pwm_duty(ATOM0_CH7_P02_7, Steer/2);

            if(RampCount<5005) RampCount++;
        }

        if(!SceenFlag)
        {
            create_Img(Thro);
            print_line(LeftLine[0],0x0010,imgInfo.LeftLineCount);
            print_line(RightLine[0],0x0010,imgInfo.RightLineCount);
            print_line(MidLine[0],0x0010,imgInfo.MidLineCount);

            if(KEY_PRESS == KEY_Get(KEY_UP))
            {
                print_big_point(LeftTurn[0], 0xd8a7);//红
                print_big_point(RightTurn[0], 0xd8a7);
            }
            else if(KEY_PRESS == KEY_Get(KEY_LEFT))
            {
                print_big_point(LeftTurn[1], 0x07ef);//绿
                print_big_point(RightTurn[1], 0x07ef);
            }
            else if(KEY_PRESS == KEY_Get(KEY_RIGHT))
            {
                print_big_point(LeftTurn[2], 0x1c9f);//蓝
                print_big_point(RightTurn[2], 0x1c9f);
            }
            else
            {
                print_big_point(LeftTurn[1], 0x07ef);//绿
                print_big_point(RightTurn[1], 0x07ef);
                print_big_point(LeftTurn[2], 0x1c9f);//蓝
                print_big_point(RightTurn[2], 0x1c9f);
                print_big_point(LeftTurn[0], 0xd8a7);//红
                print_big_point(RightTurn[0], 0xd8a7);
            }

            print_big_line1(TempLine1[0],0xd8a7,0);
            print_big_line1(TempLine2[0],0x1c9f,0);
            for(uint8 i1=0;i1<120;i1++)
            {
                testLine[i1][0] = i1;
                testLine[i1][1] = 94;
            }
            print_line(testLine[0],0x0010,120);

            print_Img_color();

            ips114_showint32(190,0, Error,4);
            ips114_showint32(190,1, LeftTFlag+RightTFlag+CircleFlag+NoHeadFlag+ThreeForkFlag,4);

            ips114_showint32(190,2,LeftTurn[0][0],4);
            ips114_showint32(190,3,RightTurn[0][0],4);

            ips114_showfloat(190,4,LeftCos,4,3);
            ips114_showfloat(190,5,RightCos,4,3);

//            ips114_showint32(190,4,RightMax,4);
//            ips114_showint32(190,5,RightTurn[0][0],4);

            print_road_type(190,6,imgInfo.roadType);
            print_road_type(190,7,imgInfo.nextroadType);

//            ips114_showint32(190,0,ThreeForkForesee[0],4);
//            ips114_showint32(190,1,ThreeForkForesee[1],4);
//            ips114_showint32(190,2,ThreeForkForesee[2],4);
//            ips114_showint32(190,3,ThreeForkForesee[3],4);
//            ips114_showint32(190,4,LeftTForesee,4);
//            ips114_showint32(190,5,RightTForesee,4);

//            ips114_showfloat(190,4,((float)(s_a_value/100))/1000,4,3);
//            ips114_showfloat(190,5,((float)(s_a_value%100))/1000,4,3);

        }
    }
}

#pragma section all restore

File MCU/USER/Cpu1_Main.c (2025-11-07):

/*********************************************************************************************************************
 * COPYRIGHT NOTICE
 * Copyright (c) 2020,逐飞科技
 * All rights reserved.
 * 技术讨论QQ群：三群：824575535
 *
 * 以下所有内容版权均属逐飞科技所有，未经允许不得用于商业用途，
 * 欢迎各位使用并传播本程序，修改内容时必须保留逐飞科技的版权声明。
 *
 * @file            main
 * @company         成都逐飞科技有限公司
 * @author          逐飞科技(QQ3184284598)
 * @version         查看doc内version文件 版本说明
 * @Software        ADS v1.2.2
 * @Target core     TC364DP
 * @Taobao          https://seekfree.taobao.com/
 * @date            2020-11-23
 ********************************************************************************************************************/

#include "headfile.h"
#include "HCI.h"
#include "IPS.h"
#include "Key.h"
#include "Motor.h"
#include "Track.h"
#include "PreDeal.h"
#include "ESP8266.h"
#pragma section all "cpu1_dsram"
//将本语句与#pragma section all restore语句之间的全局变量都放在CPU1的RAM中

extern uint8 Thro;
//int8 Error;
uint16 nowtime;
uint8 EspFlag;
int16 C1Num=0;
extern uint8 RampFlag;
extern uint8 NoRampFlag;
extern uint8 NoLowFlag;
extern int8 NowError;

extern uint8 CopyFlag;
extern uint8 Mark[4];
extern uint16 SpeedUpFlag;
extern int16 left_sum;
extern int16 ex_v1;
extern int16 ex_v2;
extern float RightCos;
extern uint8 RightTurn[4][3];

extern uint16 nowtime;
extern float speed;
extern float nowspeed;

extern motor motor_l,motor_r;
//
//extern uint16 time;
extern uint8 Cpu0InitFlag;
//
//extern uint8 LeftLine[256][2];
//extern uint8 RightLine[256][2];
extern uint8 MiddleLine[256][2];
//extern uint8 LeftTurn[4][3];
//extern uint8 RightTurn[4][3];
extern uint8 MiddleTurn[4][3];
//
//extern float LeftK[8];
//extern float RightK[8];
//
//extern uint32 mid_speed;
//extern uint32 res6;
//extern uint32 PD_P;
//
extern struct imageInformation imgInfo;

extern uint8 LeftLine1[256][2];
extern uint8 RightLine1[256][2];
extern uint8 MiddleLine1[256][2];
extern uint8 MidLine[256][2];
extern uint8 LeftTurn1[4][3];
extern uint8 RightTurn1[4][3];
extern uint8 TempLine11[256][2];
extern uint8 TempLine21[256][2];
extern int8 Error;
extern int8 preError;
extern int8 CircleCount;
extern uint16 Steer;
extern uint8 ThreeForkCount;
extern uint8 BadThreeForkFlag;
extern uint8 CircleFlag;
extern uint16 ThreeForkTime;
extern uint16 BadCrossTime;

extern struct imageInformation imgInfo1;
extern float LeftK1[8];
extern float RightK1[8];
extern uint8 RightTFlag;
extern uint8 ThreeForkFlag;
extern uint8 LeftTFlag;
extern uint8 PD_Plan;
extern uint8 GarageCount;
extern float Error_P;
extern uint16 SpeedUpFlag;
extern uint16 ChangeCount;
uint8 C2Num[2];
extern uint32 stop_time;
extern uint16 StopFlag;
extern uint32 gpt_sum;

extern int8 preError;

extern float Gyro_x;
extern float Gyro_y;
extern float Gyro_z;

extern int8 CircleMean[50];
extern uint8 CircleMeanCount;
extern uint8 SpeedUpCount;
extern uint8 ThreeForkOutFlag;
extern uint16 RampCount;

extern float LeftCos;
extern float RightCos;

int32 sumnum;

uint8 ad_sum[100]={0,};
uint8 ad_sample=0;

void core1_main(void)
{
    disableInterrupts();
    IfxScuWdt_disableCpuWatchdog(IfxScuWdt_getCpuWatchdogPassword());
    //用户在此处调用各种初始化函数等

    while(!Cpu0InitFlag);

    //等待所有核心初始化完毕
    IfxCpu_emitEvent(&g_cpuSyncEvent);
    IfxCpu_waitEvent(&g_cpuSyncEvent, 0xFFFF);
    enableInterrupts();

    while(Cpu0InitFlag!=2);

    for(uint8 i=0;i<100;i++)
    {
        data_conversion(100, 0, 0, 0, virtual_scope_data);//使用虚拟示波器数据转换函数转换数据，至多同时转换四个数据
        seekfree_wireless_send_buff(virtual_scope_data, 10); //数据转换完成后，使用无线串口发送函数将数组的内容发送出去
    }

    while (TRUE)
    {
//        ips114_showint32(190,0,motor_l.real_speed,4);
//        ips114_showint32(190,1,motor_r.real_speed,4);
//        ips114_showint32(190,2,motor_l.set_speed,4);
//        ips114_showint32(190,3,motor_r.set_speed,4);
//
        if(CircleMeanCount)
        {
            sumnum = 0;
            for(uint8 i=0;i<20;i++)
            {
                sumnum += CircleMean[i];
            }
            sumnum/=20;
        }

//        data_conversion(speed*1000,imgInfo.MidLineCount ,stop_time, StopFlag+imgInfo.StopFlag*100 , virtual_scope_data);
        data_conversion(Error+imgInfo.StopFlag*100,imgInfo.nextroadType*10,(LeftTFlag+RightTFlag+CircleFlag+ThreeForkFlag+RampFlag)*10+ThreeForkOutFlag*5, CircleCount, virtual_scope_data);

        seekfree_wireless_send_buff(virtual_scope_data, 10); //数据转换完成后，使用无线串口发送函数将数组的内容发送出去

//        if(SpeedUpCount>50) gpio_set(P02_6, 0);
//        else gpio_set(P02_6, 1);

//        uart_putchar(UART_3,Mark[0]);

//        ips114_showfloat(190,4,speed,4,3);
//        ips114_showfloat(190,5,((float)(s_a_value%100))/1000,4,3);
//        ips114_showfloat(190,4,speed,4,3);

        if(!NoLowFlag && RampFlag<=1 && Gyro_x>150) RampFlag = 2;
        if(RampFlag==2)
        {
            if(Gyro_x<-50)RampFlag = 3;
        }
        if(RampFlag==3)
        {
            if(Gyro_x>150)
            {
                RampFlag = 4;

            }
        }
        if(RampFlag==4)
        {
            if(Gyro_x<20)
            {
                RampFlag = 0;
            }
            imgInfo.nextroadType = Straight;
        }

        ad_sample = 250;
        for(uint8 i=20;i>0;i--)
        {
            ad_sum[i] = ad_sum[i-1];
            if(ad_sample>ad_sum[i]) ad_sample = ad_sum[i];
        }
        ad_sum[0] = adc_convert(ADC_8, ADC8_CH12_A44, ADC_12BIT)/20;
        if(ad_sample>ad_sum[0]) ad_sample = ad_sum[0];

        if(!NoRampFlag && ad_sample>60 && ad_sample<200 && !RampFlag &&  RampCount>300)
        {
            RampFlag = 1;
            RampCount = 0;
        }


//        ad_sample = adc_convert(ADC_8, ADC8_CH12_A44, ADC_12BIT)/20;
    }
}



#pragma section all restore

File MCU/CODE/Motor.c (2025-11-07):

#include "math.h"
#include "Motor.h"
#include "stdlib.h"
#include "string.h"
#include "headfile.h"
#include "common.h"
#include "HCI.h"
motor motor_l,motor_r; //定义电机参数
pid S3010,RS_380; //定义舵机和电机控制参数
float kp_a;
char  MID_flag=0;
float h_speed;//直道最高速度
float l_speed;//弯道最低速度
char l_transpose=0;
char r_transpose=0;
char stopflag = 1;
int16 l_filter_speed = 0;
int16 r_filter_speed = 0;
int16 l_real_speed = 0;
int16 r_real_speed = 0;
int16 l_l_filter_speed = 0;
int16 l_r_filter_speed = 0;
extern uint8 GarageFlag;

/*************************************************
函数名称: motor_init()
函数功能: 舵机、电机、编码器初始化
调用函数: 无
入口参数: 无
出口参数: 无
返回值:   无
其他:     无
***********************************************/
void motor_init(void)  //舵机、电机、编码器初始化
{
//    PWM_Config(41,271);
    RS_380.kp_value = 500 * 0.01;  //用于将人机交互中的参数转换为自己的用到的
    RS_380.ti_value = 10 * 0.01;
    RS_380.td_value = 0 * 0.01;
}

/*************************************************
函数名称: void motor_error(void)
函数功能: 电机偏差数据计算
调用函数: 无
入口参数: 无
出口参数: 无
返回值:   无
其他:     放在5ms定时中断里面
***********************************************/
void motor_error(void)
{
    static int16 l_real_speed[3] = {0};
    static int16 r_real_speed[3] = {0};
    float a[3]={0.1,0.3,0.6};
    int16 l_speed_sum = 0;
    int16 r_speed_sum = 0;

    uint8 i;
    for(i = 0; i<2; i++)
    {
        l_real_speed[i] = l_real_speed[i+1];
        r_real_speed[i] = r_real_speed[i+1];
    }
    l_real_speed[2] = motor_l.real_speed;
    r_real_speed[2] = motor_r.real_speed;
    for(i = 0; i < 3; i++)
    {
        l_speed_sum += l_real_speed[i]*a[i];
        r_speed_sum += r_real_speed[i]*a[i];
    }
    l_filter_speed =  l_speed_sum;
    r_filter_speed =  r_speed_sum;


    static int l_current_error = 0;  //左电机
    static int l_last_error = 0;
    static int l_last_last_error = 0;

    static int r_current_error = 0;  //右电机
    static int r_last_error = 0;
    static int r_last_last_error = 0;

    l_current_error = motor_l.set_speed - l_filter_speed;  //****************************************8
    r_current_error = motor_r.set_speed - r_filter_speed;

    //增量式PID控制
    //左电机
    motor_l.kp_error = l_current_error - l_last_error;
    motor_l.ti_error = l_current_error;
    motor_l.td_error = l_current_error - 2*l_last_error + l_last_last_error;
    //右电机
    motor_r.kp_error = r_current_error - r_last_error;
    motor_r.ti_error = r_current_error;
    motor_r.td_error = r_current_error - 2*r_last_error + r_last_last_error;

    if(GarageFlag)
    {
        //计算  左电机PID
           motor_l.PID_OUT = RS_380.kp_value * motor_l.kp_error * 2 + RS_380.ti_value * motor_l.ti_error + RS_380.td_value * motor_l.td_error;
           motor_l.real_duty = (int)(motor_l.real_duty + motor_l.PID_OUT);

           //计算  右电机PID
           motor_r.PID_OUT = RS_380.kp_value * motor_r.kp_error * 2 + RS_380.ti_value * motor_r.ti_error + RS_380.td_value * motor_r.td_error;
           motor_r.real_duty = (int)(motor_r.real_duty + motor_r.PID_OUT);
    }
    else
    {
        //计算  左电机PID
        motor_l.PID_OUT = RS_380.kp_value * motor_l.kp_error + RS_380.ti_value * motor_l.ti_error + RS_380.td_value * motor_l.td_error;
        motor_l.real_duty = (int)(motor_l.real_duty + motor_l.PID_OUT);

        //计算  右电机PID
        motor_r.PID_OUT = RS_380.kp_value * motor_r.kp_error + RS_380.ti_value * motor_r.ti_error + RS_380.td_value * motor_r.td_error;
        motor_r.real_duty = (int)(motor_r.real_duty + motor_r.PID_OUT);
    }
//    ips114_showint32(190,0,motor_l.real_duty,4);
//    ips114_showint32(190,1,motor_r.real_duty,4);
//    ips114_showfloat(190,1,RS_380.kp_value,4,1);
    //计算左电机
    l_last_last_error = l_last_error;
    l_last_error = l_current_error;
    //计算右电机
    r_last_last_error = r_last_error;
    r_last_error = r_current_error;
//      a = RS_380.kp_value * motor_l.kp_error;
}


/*************************************************
函数名称: void motor_control(void)
函数功能: 电机偏差数据计算
调用函数: 无
入口参数: 无
出口参数: 无
返回值:   无
其他:     占空比范围为0-10000 即0对应占空比为0  5000对应占空比50%
           放在5ms定时中断里面
***********************************************/
void motor_control(void)
{
    int setspeed_l, setspeed_r;
    char l_transpose, r_transpose;

    if(motor_l.real_duty < 0)  //左轮反转设置
    {
        setspeed_l = 0 - 5 * stopflag * motor_l.real_duty;   //stopflag 默认为0  因为智能车平时不需要电机反转 刹车时令 stopflag=1 可以制动刹车（刹车效果较强）
        l_transpose = 1;
    }
    else
    {
        l_transpose=0;
        setspeed_l = motor_l.real_duty;
    }

    if(setspeed_l > 8000)  //设置左轮上限
    {
        setspeed_l = 8000;
    }

     if(motor_r.real_duty < 0)  //右轮反转设置
     {
              setspeed_r = 0 - 5 * stopflag * motor_r.real_duty;
              r_transpose = 1;
     }
     else
     {
              setspeed_r = motor_r.real_duty;
              r_transpose=0;
     }


    if(setspeed_r > 8000)  //设置右轮上限
    {
        setspeed_r = 8000;
    }

      if(l_transpose == 1)
      {
          pwm_duty(ATOM0_CH4_P02_4, setspeed_l);               //左电机反转
          pwm_duty(ATOM0_CH3_P21_5, 0);
      }
      else
      {
            pwm_duty(ATOM0_CH4_P02_4, 0);                        //左电机正转
            pwm_duty(ATOM0_CH3_P21_5, setspeed_l);
      }

      if(r_transpose == 1)
      {
            pwm_duty(ATOM0_CH0_P21_2, setspeed_r);                        //右电机反转
            pwm_duty(ATOM0_CH1_P21_3, 0);
      }
      else
      {
            pwm_duty(ATOM0_CH0_P21_2, 0);                //右电机正转
            pwm_duty(ATOM0_CH1_P21_3, setspeed_r);
      }
}

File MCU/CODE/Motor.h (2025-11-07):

#ifndef _MOTOR_H
#define _MOTOR_H

#include "headfile.h"
#include "common.h"
//宏定义S3010通道参数
//#define S3010_TPM TPM2  //B3接舵机
//#define S3010_CH TPM_CH1
#define S3010_HZ 100
#define S3010_MID_DUTY 1350         //1310

#define RS_380_HZ 17*1000

//宏定义S3010极限参数
#define PD_OUT_DEATH 0.1   //后续修改？
#define PD_out_max 10      //后续修改？
#define S3010_OUT_MIN 1180 			//1130
#define S3010_OUT_MAX 1520 			//1490
#define S3010_OUT_MID S3010_MID_DUTY
#define motor_pid_out_max 500
#define motor_pid_out_min 100

typedef struct pid_control{
      float kp_value;  //P参数
      float ti_value;  //I参数
      float td_value;  //D参数
      float pid_out;
      float set_speed;
      float duty;
      float p_error;
      float d_error;
      float error[2];
}pid;
extern pid S3010,RS_380; //定义舵机和电机控制参数

extern float kp_a;
extern char stopflag;
typedef struct motor_control{

      uint16 set_speed;
//      float set_speed;
      int16 real_speed;

      float kp_error;
      float ti_error;
      float td_error;
      float PID_OUT;
      float real_duty;

}motor;
extern char  MID_flag;
extern motor motor_l,motor_r; //定义电机参数
extern float h_speed;
extern float l_speed;
extern int16 car_speed;
extern int16 l_filter_speed;
extern int16 r_filter_speed;
extern int16 l_real_speed;
extern int16 r_real_speed;
extern int32 r_s;
extern int32 l_s;
extern int32 S_s;
extern int32 a;
/******************函数声明**********************/
void motor_init(void);
void motor_error(void);
void motor_control(void);

#endif

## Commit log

2025-11-09 Add MCU and PC_OpenCV modules with simulation GIFs and documentation
    [sparkline.csv]
2025-11-09 Update PCB
    [(Poly)TC364_MainBoard_PCB.xls, (Poly)TC364_MainBoard_PCB_V1.1.PcbDoc, (Poly)TC364_MainBoard_PCB_V1.1.PcbLib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]

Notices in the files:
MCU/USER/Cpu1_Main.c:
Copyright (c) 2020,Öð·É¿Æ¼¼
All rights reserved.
